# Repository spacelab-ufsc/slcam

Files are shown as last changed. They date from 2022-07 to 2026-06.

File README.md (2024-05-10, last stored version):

<h1 align="center">
    SLCam
    <br>
</h1>

<h4 align="center">Camera payload designed and developed by SpaceLab.</h4>

<p align="center">
    <a href="https://github.com/spacelab-ufsc/spacelab#versioning">
        
    </a>
    <a href="https://github.com/spacelab-ufsc/slcam/releases">
        
    </a>
    <a href="https://github.com/spacelab-ufsc/slcam/releases">
        
    </a>
    <a href="https://github.com/spacelab-ufsc/slcam/commits/main">
        
    </a>
    <a href="https://github.com/spacelab-ufsc/slcam/issues">
        
    </a>
    <a href="https://github.com/spacelab-ufsc/slcam/graphs/contributors">
        
    </a>
</p>

<p align="center">
    <a href="#overview">Overview</a> •
    <a href="#repository-organization">Repository Organizarion</a> •
    <a href="#releases">Releases</a> •
    <a href="#notes">Notes</a>
</p>

<p align="center">
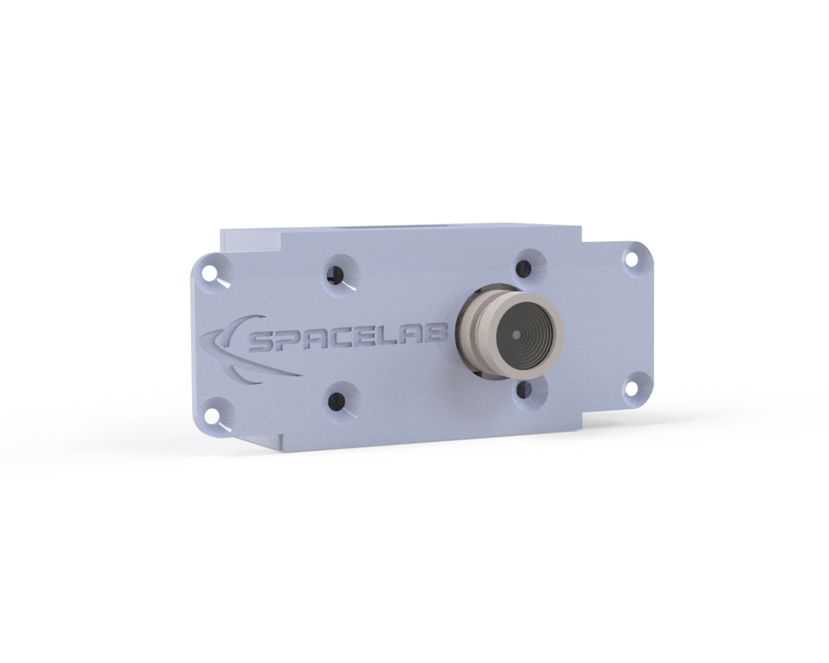
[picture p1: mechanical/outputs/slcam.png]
    
</p>

## Overview

The SLCam ("SpaceLab Camera") is a camera payload designed to be used in nanosatellite missions. The main object is to take pictures of the Earth from space. It's the first project from SpaceLab using cameras in payloads.

## Repository Organization

* docs: Technical documentation (including firmware, hardware, user guide, and datasheet).
* firmware: Firmware project (sources and configs).
* hardware: Hardware project (sources and outputs).
* mechanical: Mechanical project (sources and outputs).
* software: Software to communicate with the camera (sources).

## License

This project is open-source under three different licenses: GNU General Public License v3.0 for firmware sources, CERN Open Hardware License v2.0 for hardware and mechanical files, and CC BY-SA 4.0 for the documentation. Some third-part files and libraries are subjected to their specific terms and licenses.

## Releases

The SLCam software and hardware releases are synchronized in order to garantee compatibility. Then, using diferent versions might lead to unpredictable behavior. Refer to the [documentation](https://github.com/spacelab-ufsc/slcam/tree/main/doc) for compatibility notes.

## Notes

More info about the SpaceLab: [GitHub](https://github.com/spacelab-ufsc/spacelab) and [Website](https://spacelab.ufsc.br/en/home/).

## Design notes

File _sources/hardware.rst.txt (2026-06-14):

.. hardware.rst

   Copyright The SLCam Contributors.

   SLCam Documentation

   This work is licensed under the Creative Commons Attribution-ShareAlike 4.0
   International License. To view a copy of this license,
   visit http://creativecommons.org/licenses/by-sa/4.0/.

********
Hardware
********

This chapter presents a description of the hardware project of the SLCam payload. As the primary reference, a block diagram can be seen in :numref:`fig:block-diagram`.

.. _fig:block-diagram:

.. figure:: img/block-diagram.*
      :width: 80%
      :align: center
      :alt: Block diagram 

      Block diagram of the SLCam hardware.

As can be seen in the block diagram, the hardware design of the module can be divided into two parts: the image sensor and the camera control board.

The following sections present a further description of each part of the hardware.

Image Sensor
============

The image sensor used in the SLCam module is the Arducam Mini 2MP Plus camera module :cite:`arducam`. This module is based on the OV2640 image sensor and provides a compact and low-power solution for embedded imaging applications. It supports image resolutions up to 1600 :math:`\times` 1200 pixels and communicates with the main controller through an I\ :sup:`2`\ C and an SPI interface.

In addition to integrating the image sensor itself, the module also includes onboard FIFO memory, allowing image buffering and simplified data acquisition by the host microcontroller. Due to its reduced size, low power consumption, and ease of integration, the Arducam Mini 2MP Plus was selected as the primary imaging device for the SLCam payload.

A photograph of the Arducam Mini 2MP Plus module is shown in :numref:`fig:arducam`. The top and bottom view of the board can also be seen in :numref:`fig:arducam-top-bottom`.

.. _fig:arducam:

.. figure:: img/arducam-2mp.png
      :width: 50%
      :align: center
      :alt: Arducam Mini 2MP

      Arducam Mini 2MP Plus.

.. _fig:arducam-top-bottom:

.. subfigure:: AB
    :layout-sm: A|B
    :gap: 8px
    :subcaptions: below
    :name: arducam_board
    :class-grid: outline
    :align: center

    .. image:: img/arducam-top.jpg
        :width: 70%
        :align: center
        :alt: Top view.

    .. image:: img/arducam-bottom.jpg
        :width: 70%
        :align: center
        :alt: Bottom view.

    Arducam Mini 2MP Plus top and bottom view.

The internal architecture of the Arducam Mini 2MP Plus module is illustrated in the block diagram shown in :numref:`fig:arducam-block-diagram`. The module is centered around the OV2640 image sensor and the ArduChip controller, which is responsible for image acquisition, buffering, and communication with the host system.

.. _fig:arducam-block-diagram:

.. figure:: img/arducam-block-diagram.png
      :width: 100%
      :align: center
      :alt: Block diagram Arducam

      Block diagram of the Arducam Mini 2MP Plus.

The image sensor is connected to the ArduChip through a dedicated camera interface, responsible for receiving pixel data and synchronization signals. Internally, the ArduChip includes a Frame Buffer Finite State Machine (FSM) and memory timing control logic, which manage the storage and retrieval of image data from the external FIFO memory. This architecture allows complete image frames to be temporarily buffered before being transmitted to the host microcontroller.

Communication with the host system is performed through an SPI slave interface, using the standard signals CS, MISO, MOSI, and SCLK. Additionally, the image sensor configuration is performed through an I\ :sup:`2`\ C-compatible interface using the SDA and SCL signals. A register module is also available inside the ArduChip, enabling configuration and control of the camera operation and memory management functions.

The connection between the Arducam module and the control board is made using an 8-pin vertical header connector. Since the Arducam module originally comes with a horizontal pin header connector, it must be replaced with a vertical connector during the assembly of the SLCam device.

For integration purposes, the dimensions of the Arducam board are available in :numref:`fig:arducam-dimensions`.

.. _fig:arducam-dimensions:

.. figure:: img/arducam-dimensions.png
      :width: 50%
      :align: center
      :alt: Arducam Mini 2MP Dimensions

      Arducam Mini 2MP Plus dimensions.

Controller Board
================

The camera control board is responsible for managing the operation of the SLCam module and interfacing the image sensor with external systems. As illustrated in the block diagram, the control board is centered around the STM32F103C8T6 microcontroller, which performs image acquisition control, communication management, data processing, and system supervision. The microcontroller communicates with the image sensor through SPI and I\ :sup:`2`\ C interfaces, using a dedicated image sensor connector that also provides the 3V3 power supply required by the camera module.

For non-volatile data storage, the control board includes a W25Q128JVSIM NOR Flash memory device connected through the SPI bus. This memory is used for image storage, buffering, and firmware-related data retention. External communication with host systems can be performed through both SPI and CAN interfaces, providing redundant communication channels for control and image transfer operations. The CAN interface is implemented using the TCAN330GD CAN transceiver, which provides the physical layer interface between the microcontroller and the external CAN bus network.

The board also provides dedicated UART and JTAG connectors for debugging and firmware programming purposes. The UART interface allows access to system logs and command-line interaction, while the JTAG connector enables firmware upload and low-level debugging of the microcontroller.

Power distribution and protection are managed through the TPS2010AD power switch device, which controls the power supplied to the image sensor module. The switch is controlled by a GPIO signal from the microcontroller, allowing the firmware to enable or disable the camera module dynamically for power management and fault recovery purposes. Together, these components form a compact and modular camera controller architecture suitable for embedded and small satellite applications.

A picture of the controller board is shown in :numref:`fig:controller`.

.. _fig:controller:

.. figure:: img/controller-overview.png
      :width: 50%
      :align: center
      :alt: Controller board

      Controller board.

A list with the components and part numbers of the controller board is available in :numref:`tab:controller-bom`.

.. _tab:controller-bom:

.. list-table:: Components of the controller board.
   :widths: 30 35 25 10
   :width: 100%
   :align: center
   :header-rows: 1

   * * Component
     * Description
     * Part Number
     * Quantity
   * * Microcontroller
     * ARM Cortex M3
     * STM32F103C8T6
     * 1
   * * Flash Memory
     * NOR 128 Mbit
     * W25Q128JVSIM TR
     * 1
   * * Switch
     * Load switch
     * TPS2010AD
     * 1
   * * CAN Transceiver
     * CAN transceiver
     * TCAN330GD
     * 1
   * * SPI/3V3 Connector
     * PicoBlade 6 pin
     * 532610671
     * 1
   * * UART Connector
     * PicoBlade 3 pin
     * 532610371
     * 1
   * * CAN Connector
     * PicoBlade 3 pin
     * 532610371
     * 1
   * * Image Sensor Connector
     * Female header 8 pin straight
     * -
     * 1
   * * JTAG Connector
     * Male header 4 pin angled
     * -
     * 1
   * * Crystal
     * 8 MHz crystal
     * ECS-80-10-33-CHN-TR3
     * 1

Printed Circuit Board
*********************

The controller board PCB was developed using the KiCad v5 tool :cite:`kicad` and was designed as a compact four-layer board. The multilayer structure improves signal integrity, simplifies power distribution, and reduces electromagnetic interference, which is particularly important for embedded systems operating with high-speed digital interfaces such as SPI and CAN.

The PCB was designed using standard FR-4 material with a total thickness of 1.6 mm. The engineering model uses a HASL (Hot Air Solder Leveling) surface finish, while the flight model is planned to use an ENIG (Electroless Nickel Immersion Gold) finish to improve corrosion resistance and soldering reliability. No special dielectric or impedance-controlled stack-up requirements were necessary for the current design.

Mechanically, the controller board measures 41.7 :math:`\times` 27.4 mm and includes four mounting holes with a diameter of 3.2 mm, allowing secure integration into the payload mechanical structure. The compact dimensions of the PCB contribute to the reduced size and mass of the SLCam module, making it suitable for small satellite and embedded imaging applications.

Top and bottom views of the controller board are presented in :numref:`fig:controller-board-top-bottom`, highlighting the component placement and routing distribution across the PCB layers.

.. _fig:controller-board-top-bottom:

.. subfigure:: AB
    :layout-sm: A|B
    :gap: 8px
    :subcaptions: below
    :name: controler_board
    :class-grid: outline
    :align: center

    .. image:: img/controller-top.png
        :width: 60%
        :align: center
        :alt: Top view.

    .. image:: img/controller-bottom.png
        :width: 60%
        :align: center
        :alt: Bottom view.

    Controller board top and bottom view.

Integration Between the Image Sensor and the Controller Board
=============================================================

The SLCam module is composed of two independent electronic boards: the Arducam Mini 2MP Plus image sensor board and the custom-developed controller board. The integration between these two boards is illustrated in :numref:`fig:boards-integration`.

.. _fig:boards-integration:

.. figure:: img/boards-integration.png
   :width: 60%
   :align: center
   :alt: Boards integration

   Integration between the Arducam image sensor board and the controller board.

The controller board is positioned below the image sensor module and is responsible for power distribution, communication management, image acquisition control, and external interfacing of the SLCam module. The Arducam board is mounted above the controller board using metallic spacers that provide mechanical support, structural rigidity, and controlled spacing between the two PCBs.

The electrical connection between both boards is performed through a vertical pin header interface. Through this connector, the controller board provides the required 3V3 power supply to the image sensor module and establishes the SPI and I\ :sup:`2`\ C communication buses used for image transfer and camera configuration. The SPI interface is responsible for image data acquisition from the ArduChip FIFO memory, while the I\ :sup:`2`\ C bus is used for configuring the OV2640 image sensor registers and operating parameters.

As shown in :numref:`fig:boards-integration`, the optical axis of the camera module is aligned with the center of the mechanical enclosure opening, allowing unobstructed image acquisition. The stacked PCB arrangement contributes to reducing the overall footprint of the payload while maintaining accessibility to the external electrical interfaces located on the controller board.

Additionally, insulating foam spacers are positioned between the boards to reduce mechanical vibrations, minimize stress concentration during assembly, and prevent unintended contact between electronic components mounted on opposite PCB surfaces. This integration approach results in a compact, lightweight, and mechanically robust imaging subsystem suitable for embedded and nanosatellite applications.

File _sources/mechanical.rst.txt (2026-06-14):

.. mechanical.rst

   Copyright The SLCam Contributors.

   SLCam Documentation

   This work is licensed under the Creative Commons Attribution-ShareAlike 4.0
   International License. To view a copy of this license,
   visit http://creativecommons.org/licenses/by-sa/4.0/.

**********
Mechanical
**********

This chapter describes the mechanical design of the SLCam module, including the structural architecture, manufacturing process, materials, dimensions, and external mechanical interfaces. The mechanical project was developed using the SolidWorks CAD software :cite:`solidworks`, allowing the creation of the complete three-dimensional model of the payload and the verification of the assembly and integration requirements.

The SLCam mechanical structure was designed to provide adequate protection for the electronic boards and optical components while maintaining reduced size and mass, which are critical requirements for nanosatellite applications. The mechanical assembly is composed of a machined aluminum enclosure, internal support spacers, fastening screws, and the optical opening for the camera lens. All parts of the mechanical assembly are shown in :numref:`fig:slcam-parts`.

.. _fig:slcam-parts:

.. figure:: img/assembly-parts.jpg
   :width: 100%
   :align: center
   :alt: SLCam parts

   Exploded view of the SLCam mechanical assembly.

As illustrated in :numref:`fig:slcam-parts`, the mechanical structure is composed of two main enclosure parts: the main body and the bottom cover. The main body accommodates the controller board and the image sensor assembly, while the removable cover provides access to the internal electronics during integration and maintenance procedures. Metallic spacers and fastening screws are used to mechanically secure the printed circuit boards and maintain the required alignment between the controller board and the image sensor module.

The optical interface is located on the upper surface of the enclosure, where a circular opening allows the camera lens to capture images outside the module. The enclosure also includes external openings for electrical connectors and integration interfaces. Additionally, engraved inscriptions are present on the external surfaces of the case for identification and traceability purposes.

The enclosure was manufactured from 7075 aluminum alloy using a CNC milling process. This material was selected due to its high mechanical strength, low density, and suitability for aerospace and embedded applications. After machining, all external and internal surfaces of the enclosure received an anodization treatment to improve corrosion resistance, surface hardness, and long-term durability.

The SLCam module has compact dimensions suitable for CubeSat-class payloads. The dimensions of the main structural core are 54.0 :math:`\times` 26.1 :math:`\times` 34.1 mm, while the overall envelope dimensions are 82.2 :math:`\times` 34.8 :math:`\times` 34.1 mm. The total mass of the module is approximately 67 g, including the enclosure, electronics, fasteners, and optical assembly.

For structural integration into the satellite platform, the mechanical case includes mounting holes compatible with M3 screws, allowing secure attachment to the spacecraft structure. The positions and spacing of these mounting interfaces are described in the following sections.

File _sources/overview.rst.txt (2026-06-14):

.. overview.rst

   Copyright The SLCam Contributors.

   SLCam Documentation

   This work is licensed under the Creative Commons Attribution-ShareAlike 4.0
   International License. To view a copy of this license,
   visit http://creativecommons.org/licenses/by-sa/4.0/.

********
Overview
********

The SLCam is a compact camera payload developed by SpaceLab at the Federal University of Santa Catarina (UFSC) for nanosatellite and embedded imaging applications. The primary objective of the module is to capture images of the Earth from orbit, providing a low-cost and modular imaging solution suitable for CubeSat-class missions and technology demonstration platforms. The SLCam project also represents the first SpaceLab payload specifically designed around camera-based image acquisition systems. A picture of the camera module can be seen in :numref:`fig:slcam-mounted`.

.. _fig:slcam-mounted:

.. figure:: img/slcam-small.png
      :width: 70%
      :align: center
      :alt: SLCam 

      SLCam.

The payload architecture is divided into two main subsystems: the image sensor module and the camera controller board. The imaging subsystem is based on the Arducam Mini 2MP Plus module, which integrates the OV2640 image sensor and onboard FIFO memory for image buffering. The controller board, built around the STM32F103C8T6 microcontroller, is responsible for image acquisition control, communication management, data storage, and system supervision. The module also includes external NOR Flash memory for image storage and supports both SPI and CAN interfaces for communication and image transfer.

From the software perspective, the SLCam firmware is organized using a layered architecture based on FreeRTOS, separating low-level hardware abstraction, peripheral drivers, device management, and application tasks. The firmware also incorporates software validation mechanisms such as static analysis, unit testing, and hardware integration testing, contributing to the reliability and maintainability of the system. Automated verification workflows are executed through GitHub Actions, enabling continuous integration and validation of the firmware throughout the development process.

Mechanically, the payload was designed as a compact and lightweight module suitable for constrained satellite platforms. The controller PCB uses a four-layer FR-4 stack-up and integrates all the required interfaces for programming, debugging, control, and data transfer. Together, the hardware, firmware, mechanical, and software components form a complete imaging payload platform intended for research, educational, and experimental space missions.

Specifications
==============

The SLCam is a compact imaging payload designed for nanosatellite and embedded applications. The module integrates the Arducam Mini 2MP Plus image sensor together with a dedicated controller board based on the STM32F103C8T6 ARM Cortex-M3 microcontroller operating at 72 MHz. The system also includes external NOR Flash memory for non-volatile image storage and supports multiple communication interfaces for control, debugging, and programming purposes.

The main specifications of the SLCam module are available in :numref:`tab:slcam-specs`.

.. _tab:slcam-specs:

.. list-table:: General specifications of the SLCam module.
    :widths: 30 30
    :width: 60%
    :align: center
    :header-rows: 1

    *
      - **Parameter**
      - **Value**
    *
      - *Sensor type*
      - RGB
    *
      - *Image Sensor*
      - OV2640
    *
      - *Pixel size*
      - 2.2 :math:`\times` 2.2 :math:`\mu` m
    *
      - *Max. Resolution*
      - 1600 :math:`\times` 1200 px
    *
      - *Shutter*
      - Rolling Shutter
    *
      - *Field of View (FoV)*
      - :math:`68^{\circ}` (6 mm) (**TBC**)
    *
      - *Processor*
      - STM32 ARM Cortex-M3
    *
      - *Storage*
      - 16 MB (Flash NOR)
    *
      - *Power Supply*
      - 3V3 @ 140 mA (**TBC**)
    *
      - *Control/Data Interface*
      - SPI and/or CAN
    *
      - *Debug Interface*
      - UART
    *
      - *Programming*
      - JTAG
    *
      - *Operating System*
      - FreeRTOS
    *
      - *Dimensions*
      - | 54.0 :math:`\times` 26.1 :math:`\times` 34.1 mm (main core)
        | 82.2 :math:`\times` 34.8 :math:`\times` 34.1 mm (envelope)
    *
      - *Weight*
      - 67 g

Product tree
============

The product tree of the SLCam payload can be divided into five branches: hardware, firmware, mechanical, software and documentation. A diagram of the product tree is available in :numref:`fig:product-tree`.

.. _fig:product-tree:

.. figure:: img/product-tree.*
      :width: 100%
      :align: center
      :alt: Product tree

      Product tree of the SLCam Payload.

Each branch and element of the product tree are described in the next chapters of this documentation.

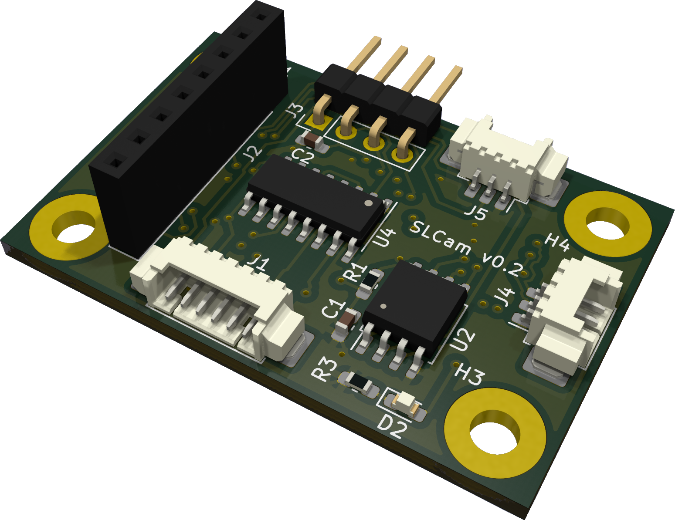
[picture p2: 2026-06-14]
_images/controller-overview.png

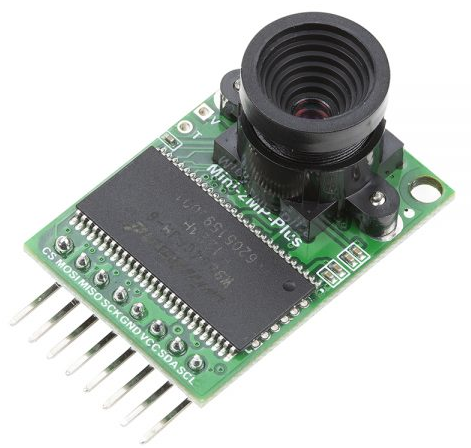
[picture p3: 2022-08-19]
_images/arducam-2mp.png

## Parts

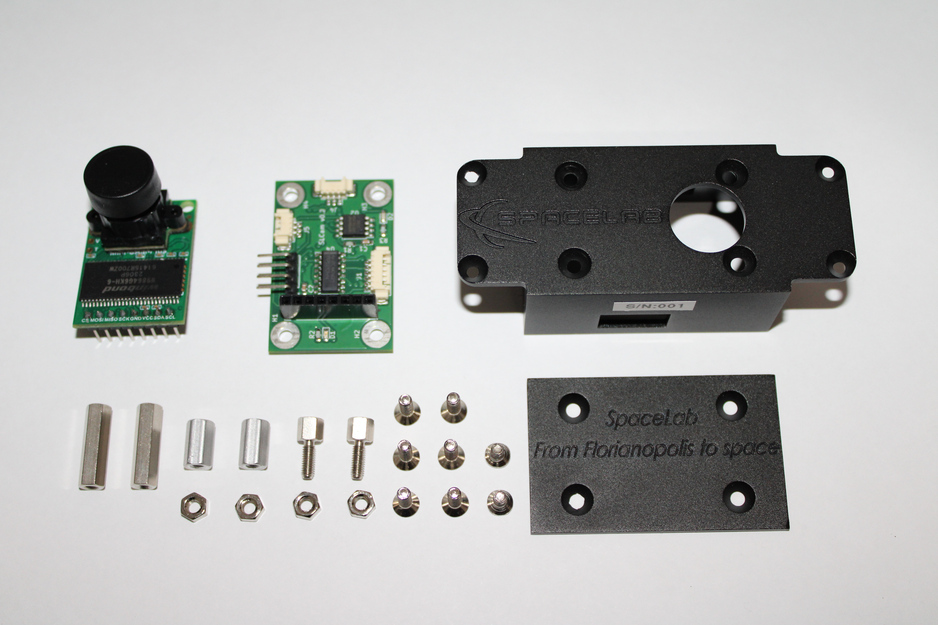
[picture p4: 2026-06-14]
_images/assembly-parts.jpg

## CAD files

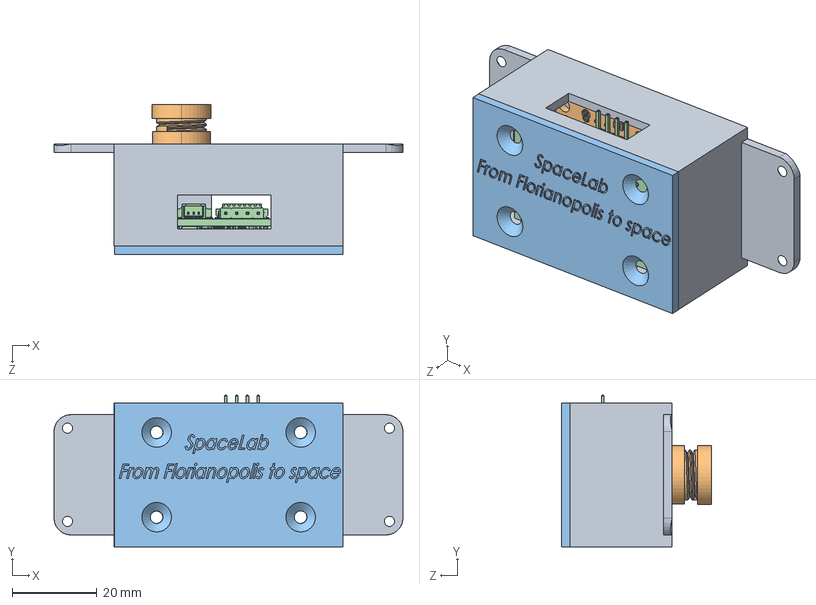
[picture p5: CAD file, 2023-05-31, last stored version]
mechanical/slb-slc-case.sldasm
82.4 x 35.8 x 35.3 mm
Placa traseira camera
UC-474B0067
Peça2

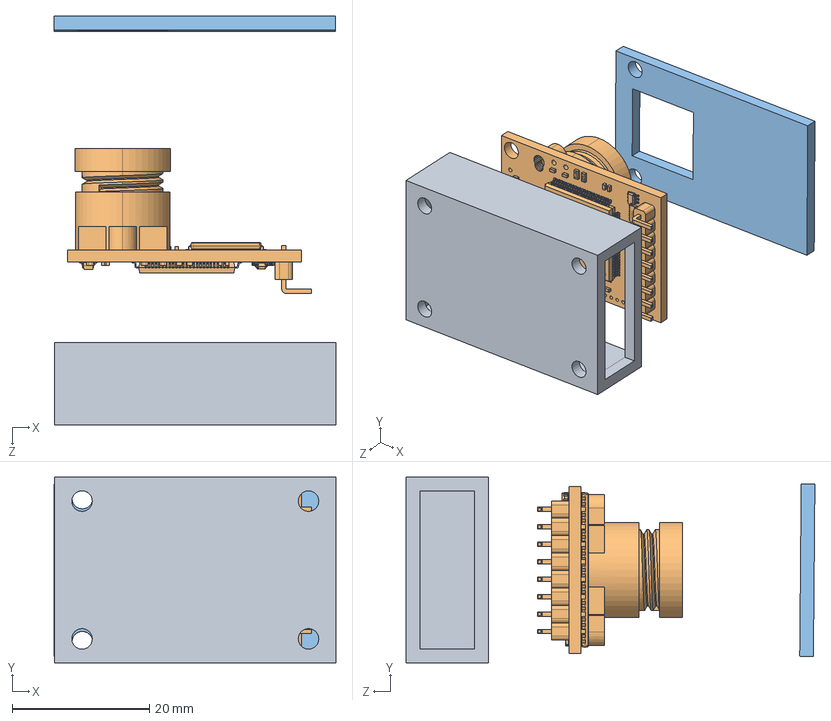
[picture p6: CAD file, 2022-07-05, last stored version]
mechanical/slcam-mount.sldasm
41.1 x 27.1 x 59.6 mm
Placa traseira camera
UC-474(B0067)
Placa frontal camera

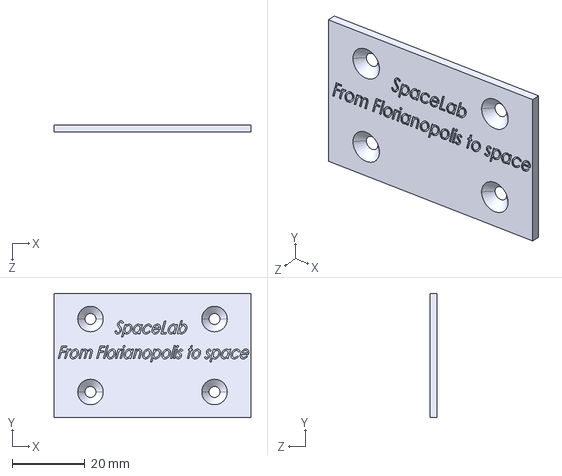
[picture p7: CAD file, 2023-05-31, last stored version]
mechanical/outputs/slb-slc-case-back.step
54.0 x 34.0 x 2.00 mm

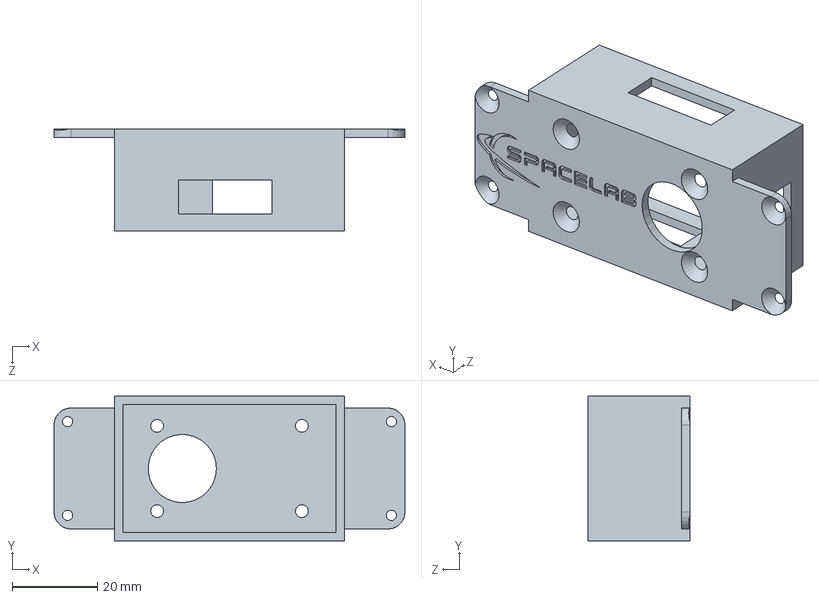
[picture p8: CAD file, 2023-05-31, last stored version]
mechanical/slb-slc-case-front.sldprt
82.4 x 34.0 x 24.0 mm

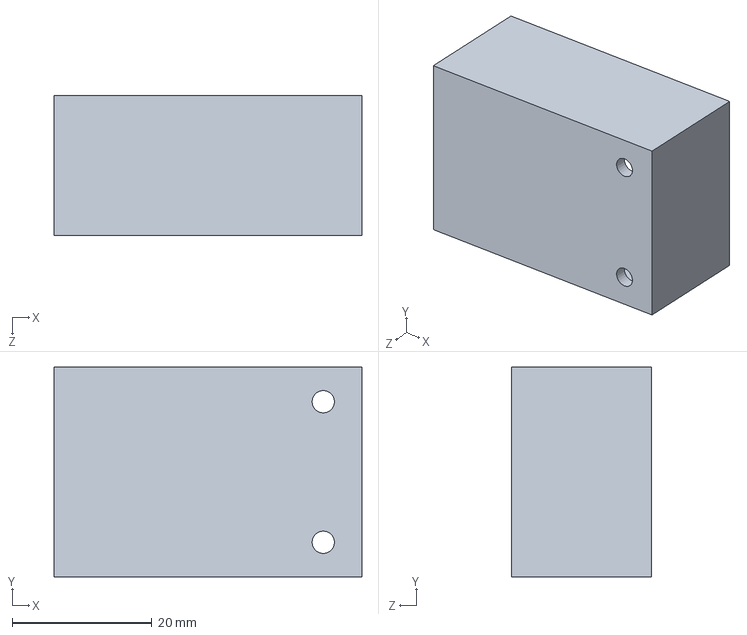
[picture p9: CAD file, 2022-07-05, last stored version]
mechanical/slcam-front-shield-v2.sldprt
44.0 x 30.0 x 20.0 mm

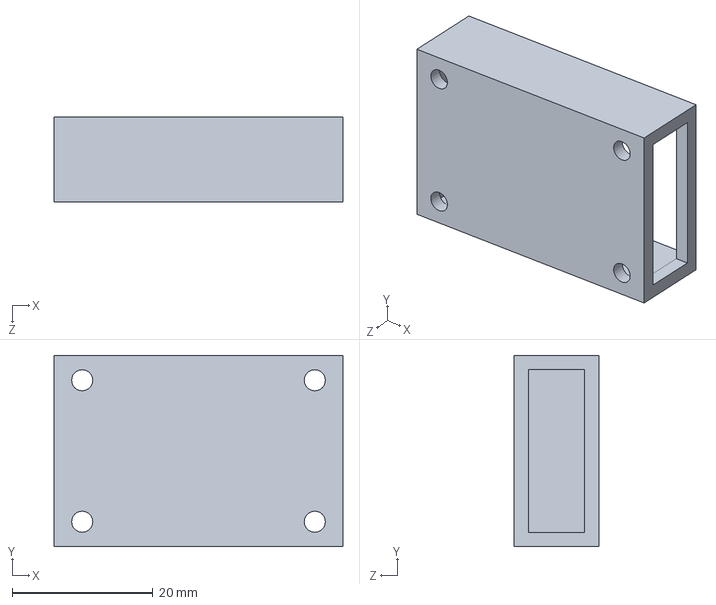
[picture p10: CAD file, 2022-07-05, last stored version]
mechanical/Placa traseira camera.SLDPRT
41.0 x 27.1 x 12.0 mm

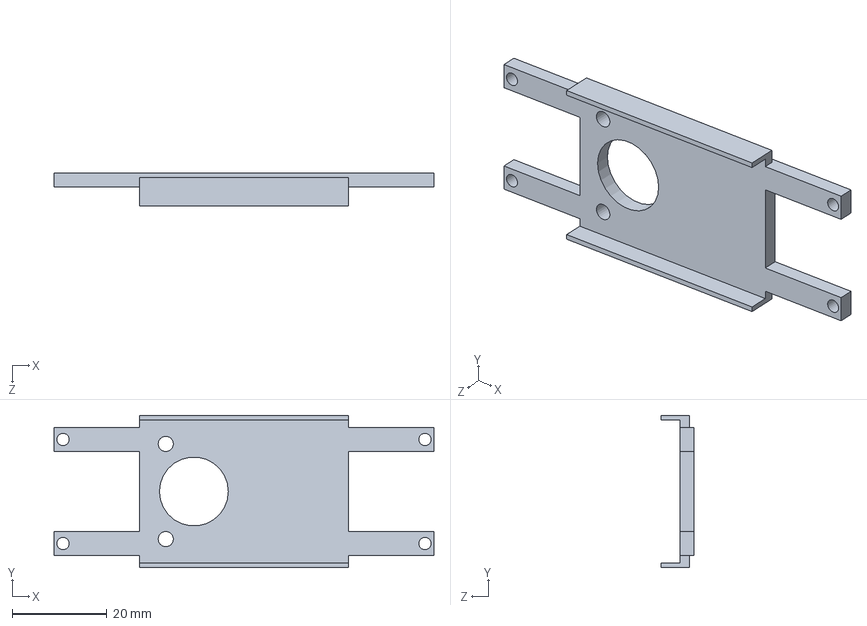
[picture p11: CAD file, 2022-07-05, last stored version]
mechanical/Placa traseira camera_V2.SLDPRT
80.0 x 32.1 x 7.00 mm

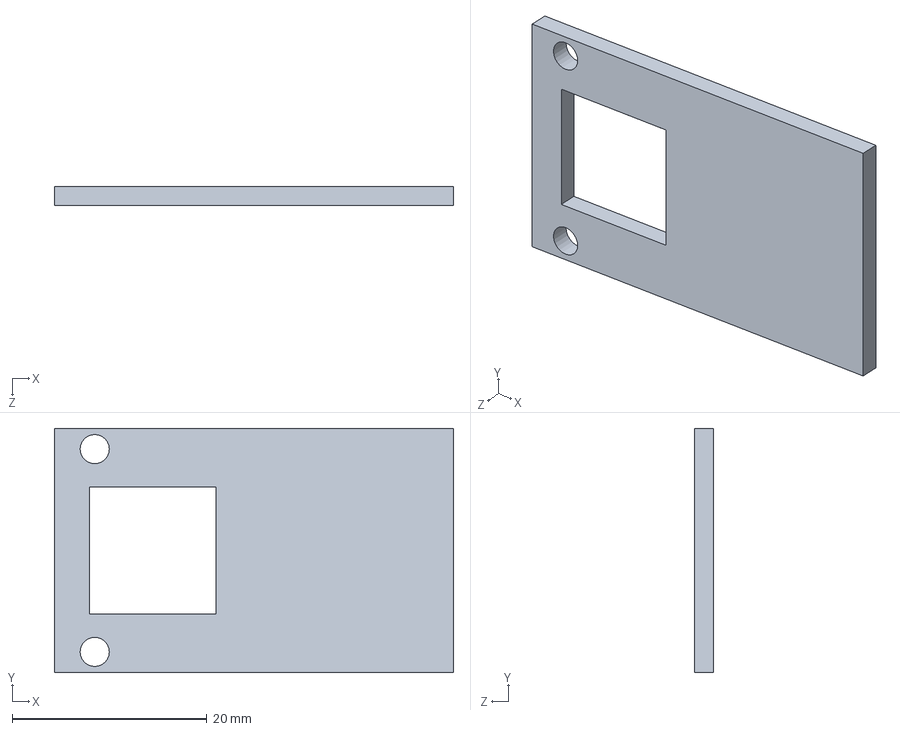
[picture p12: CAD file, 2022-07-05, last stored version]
mechanical/Placa frontal camera.SLDPRT
41.0 x 25.1 x 2.00 mm

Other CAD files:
mechanical/outputs/slb-slc-case-front.step
mechanical/Placa frontal camera_V2.STL
mechanical/Placa traseira camera_V2.STL
mechanical/slb-slc-case-back.slddrw
mechanical/slb-slc-case-front.slddrw
mechanical/slb-slc-case.sldprt
mechanical/slcam-back-shield-v2.stl
mechanical/slcam-front-shield-v2.stl

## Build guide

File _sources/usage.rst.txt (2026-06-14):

.. usage.rst

   Copyright The SLCam Contributors.

   SLCam Documentation

   This work is licensed under the Creative Commons Attribution-ShareAlike 4.0
   International License. To view a copy of this license,
   visit http://creativecommons.org/licenses/by-sa/4.0/.

******************
Usage Instructions
******************

Assembly
========

This section describes the recommended assembly procedure for the SLCam module. The assembly sequence presented below follows the order illustrated in the figures and ensures the correct mechanical alignment between the controller board, the image sensor module, and the external enclosure.

#. **Prepare the base plate and fastening screws**

Start the assembly by positioning the four mounting screws into the base plate holes, as shown in :numref:`fig:assembly-step1`.

.. _fig:assembly-step1:

.. figure:: img/step1.jpg
      :width: 100%
      :align: center
      :alt: Assembly step 1

      Step 1 of the assembly sequence.

#. **Fix the screws using nuts**

Secure the screws to the base plate using the corresponding nuts on the opposite side of the plate. This step creates the mechanical support structure used for mounting the electronic boards.

.. _fig:assembly-step2:

.. figure:: img/step2.jpg
      :width: 100%
      :align: center
      :alt: Assembly step 2

      Step 2 of the assembly sequence.

#. **Install the controller board**

Place the controller board onto the mounted screws, aligning the PCB mounting holes with the screw positions, as illustrated in :numref:`fig:assembly-step3`.

.. _fig:assembly-step3:

.. figure:: img/step3.jpg
      :width: 100%
      :align: center
      :alt: Assembly step 3

      Step 3 of the assembly sequence.

#. **Install the metallic spacers**

Attach the metallic spacers above the controller board using the threaded screws. These spacers define the vertical distance between the controller board and the image sensor module while also providing mechanical rigidity to the structure.

.. _fig:assembly-step4:

.. figure:: img/step4.jpg
      :width: 100%
      :align: center
      :alt: Assembly step 4

      Step 4 of the assembly sequence.

#. **Prepare the image sensor module**

Install the fastening screws and support spacers on the Arducam image sensor board. Protective foam pads may also be positioned near the mounting points to reduce mechanical stress and vibrations during operation.

.. _fig:assembly-step5:

.. figure:: img/step5.jpg
      :width: 100%
      :align: center
      :alt: Assembly step 5

      Step 5 of the assembly sequence.

#. **Mount the image sensor board**

Position the image sensor board above the controller board, aligning the spacers and connector interfaces. The camera module should remain parallel to the controller board to ensure proper optical alignment.

.. _fig:assembly-step6:

.. figure:: img/step6.jpg
      :width: 100%
      :align: center
      :alt: Assembly step 6

      Step 6 of the assembly sequence.

#. **Connect the image sensor interface**

Carefully connect the image sensor board to the controller board through the dedicated header connector. Verify that all connector pins are properly aligned before applying force to the assembly.

.. _fig:assembly-step7:

.. figure:: img/step7.jpg
      :width: 100%
      :align: center
      :alt: Assembly step 7

      Step 7 of the assembly sequence.

#. **Verify the internal assembly**

After the installation of both electronic boards, inspect the mechanical alignment, connector engagement, and spacer fixation. An assembled internal structure is shown in :numref:`fig:assembly-step8`.

.. _fig:assembly-step8:

.. figure:: img/step8.jpg
      :width: 100%
      :align: center
      :alt: Assembly step 8

      Step 8 of the assembly sequence.

#. **Insert the assembly into the enclosure**

Position the assembled electronic structure inside the aluminum enclosure. Ensure that the camera lens is aligned with the optical opening of the case and that the external connectors are properly positioned relative to the case openings.

.. _fig:assembly-step9:

.. figure:: img/step9.jpg
      :width: 100%
      :align: center
      :alt: Assembly step 9

      Step 9 of the assembly sequence.

#. **Fix the top cover**

Install the top cover of the enclosure and secure it using the fastening screws, as shown in :numref:`fig:assembly-step10`.

.. _fig:assembly-step10:

.. figure:: img/step10.jpg
      :width: 100%
      :align: center
      :alt: Assembly step 10

      Step 10 of the assembly sequence.

#. **Final inspection**

After completing the assembly, perform a final inspection of the module, verifying the mechanical fixation, connector accessibility, optical alignment, and enclosure closure integrity. The final assembled SLCam module is illustrated in :numref:`fig:assembly-step11`.

.. _fig:assembly-step11:

.. figure:: img/step11.jpg
      :width: 100%
      :align: center
      :alt: Assembly step 11

      Step 11 of the assembly sequence.

The assembly procedure described above is intended for laboratory integration and prototype assembly. During flight-model assembly, additional procedures such as torque control, thread-locking compounds, cleanliness verification, and vibration-resistant fixation methods may also be required.

Firmware Upload
===============

.. note::
   TODO

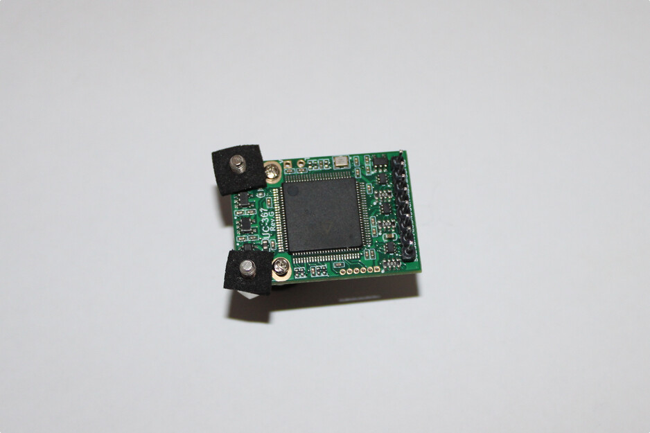
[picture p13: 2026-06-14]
_images/step7.jpg

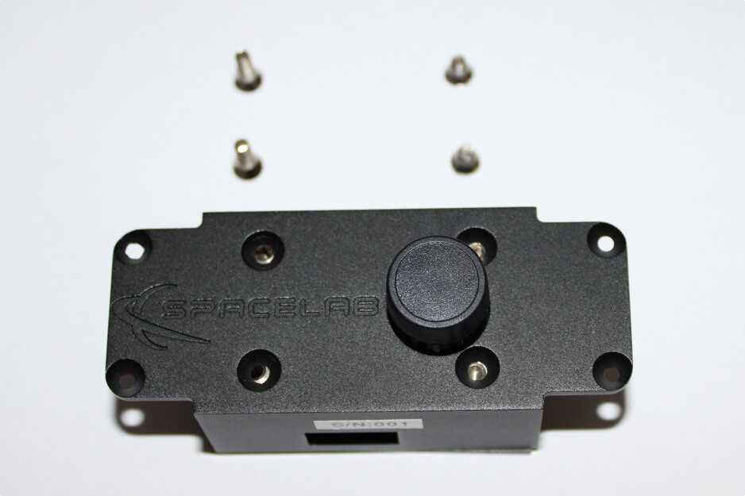
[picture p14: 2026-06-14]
_images/step10.jpg

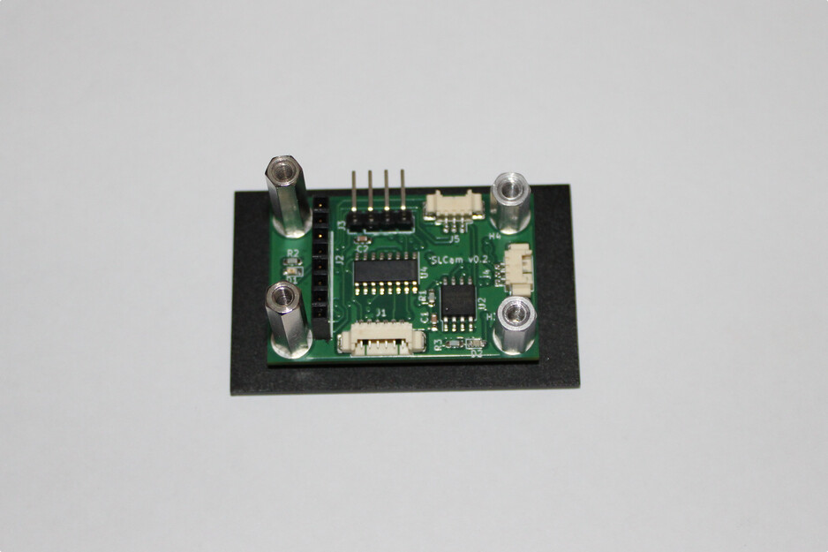
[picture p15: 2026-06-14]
_images/step5.jpg

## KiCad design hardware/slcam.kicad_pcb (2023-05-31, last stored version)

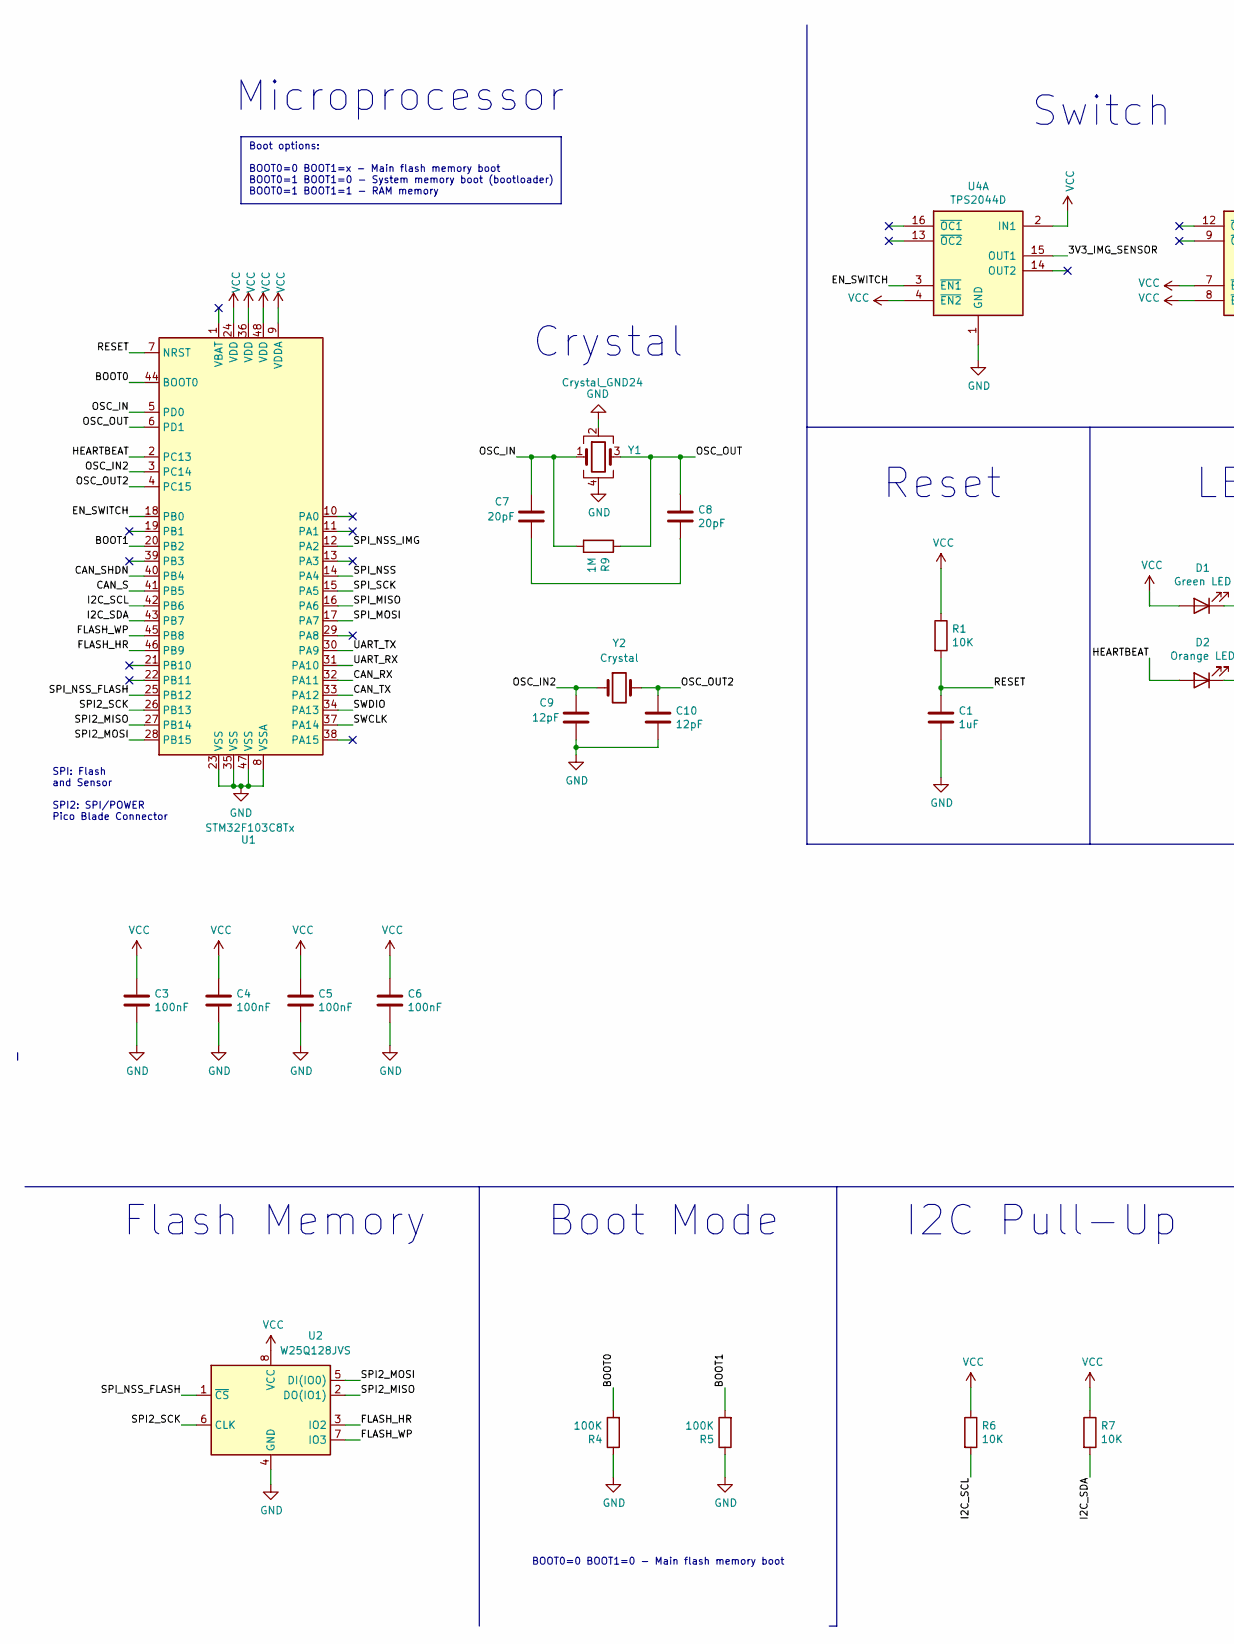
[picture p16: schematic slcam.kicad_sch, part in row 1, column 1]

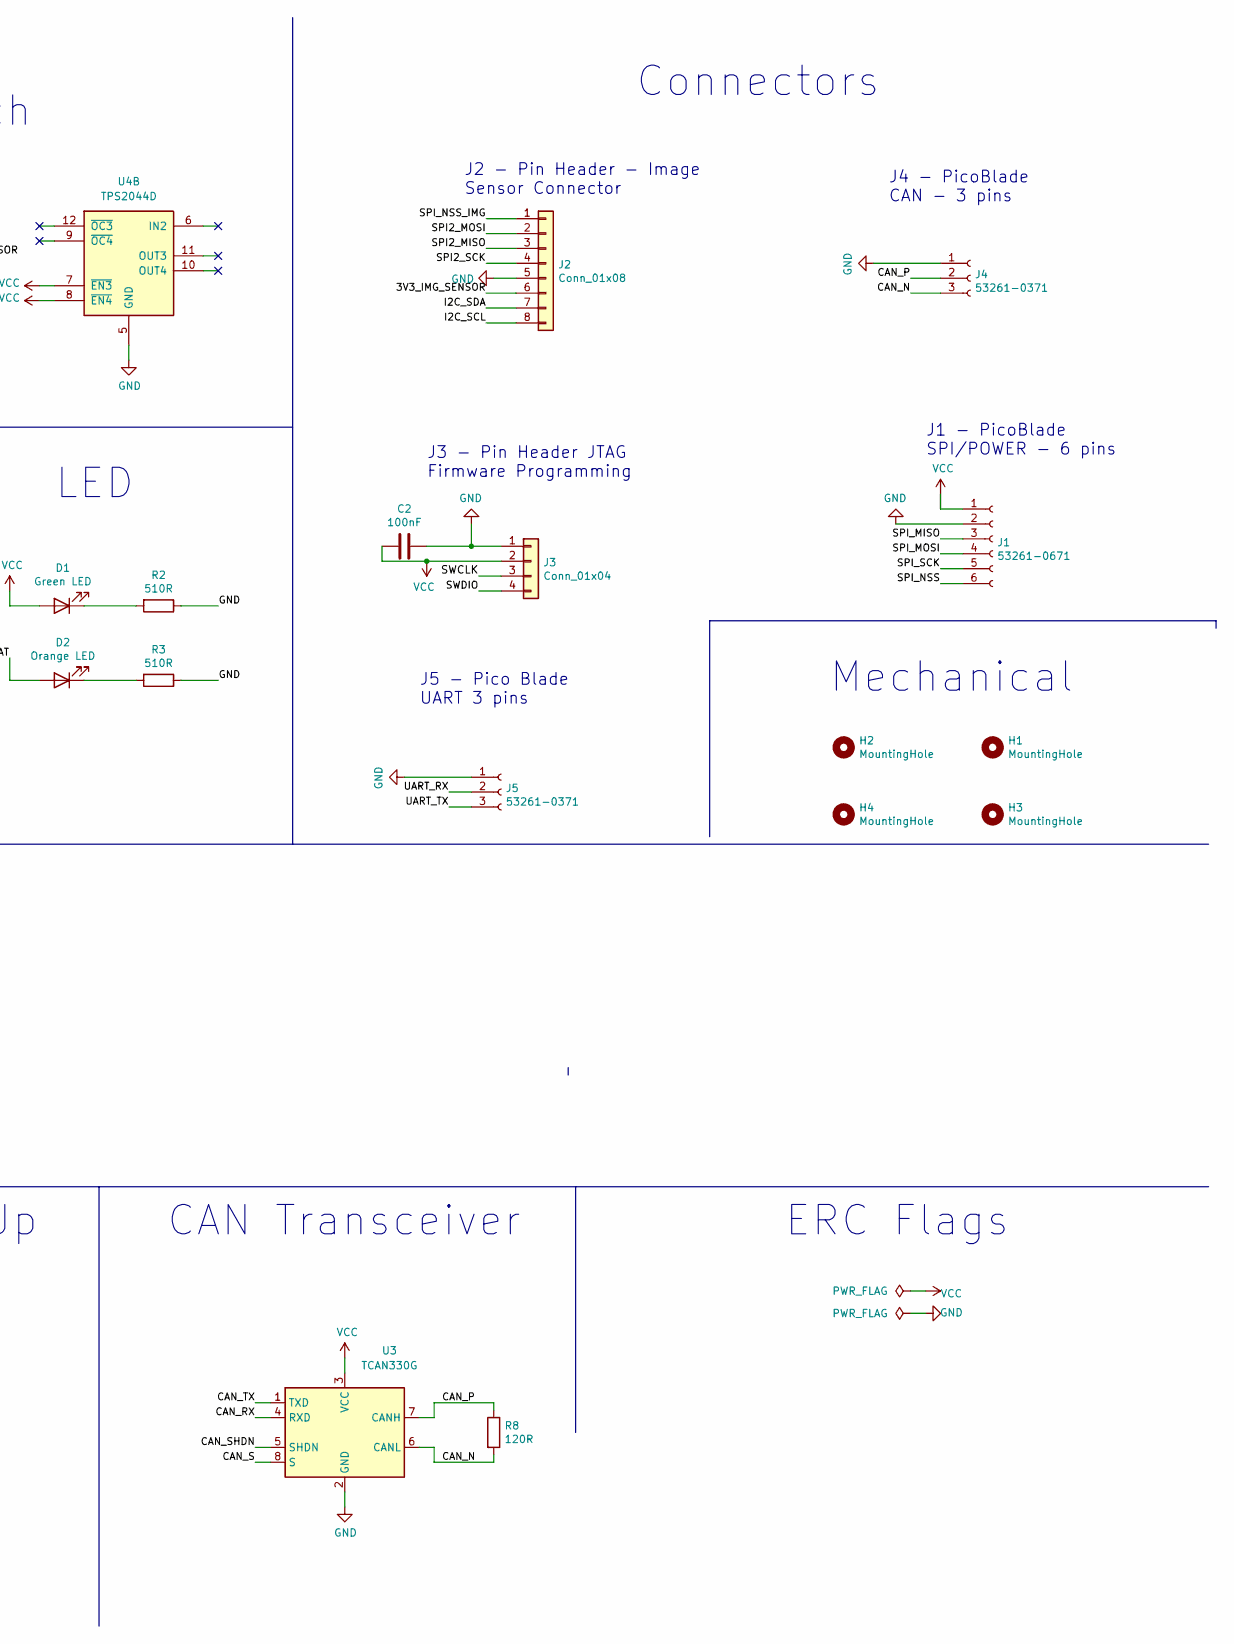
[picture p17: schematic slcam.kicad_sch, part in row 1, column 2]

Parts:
C1: 1uF; C_0603_1608Metric_Pad1.05x0.95mm_HandSolder; Partnumber GCJ188R71E105KA01D
C2, C3, C4, C5, C6: 100nF; C_0603_1608Metric_Pad1.05x0.95mm_HandSolder; Partnumber C0603C104K5RAC3121
C7, C8: 20pF; C_0603_1608Metric_Pad1.05x0.95mm_HandSolder; Partnumber CBR06C200J5GACAUTO
C9, C10: 12pF; C_0603_1608Metric_Pad1.08x0.95mm_HandSolder; Partnumber CL21C120FBANNNC
D1: Green LED; LED_0603_1608Metric_Pad1.05x0.95mm_HandSolder; Partnumber 150060VS75003
D2: Orange LED; LED_0603_1608Metric_Pad1.05x0.95mm_HandSolder; Partnumber CSL1901DW1
H1, H2, H3, H4: MountingHole; MountingHole_3.2mm_M3_Pad
J1: 53261-0671; Molex_PicoBlade_53261-0671_1x06-1MP_P1.25mm_Horizontal; Partnumber 53261-0671
J2: Conn_01x08; PinHeader_1x08_P2.54mm_Vertical; Partnumber SSQ-108-03-G-S
J3: Conn_01x04; PinHeader_1x04_P2.54mm_Vertical; Partnumber 5-146305-4
J4, J5: 53261-0371; Molex_PicoBlade_53261-0371_1x03-1MP_P1.25mm_Horizontal; Partnumber 53261-0371
R1, R6, R7: 10K; R_0603_1608Metric_Pad1.05x0.95mm_HandSolder; Partnumber MCT06030C1002FP500
R2, R3: 510R; R_0603_1608Metric_Pad1.05x0.95mm_HandSolder; Partnumber MCT06030C5100FP500
R4, R5: 100K; R_0603_1608Metric_Pad1.05x0.95mm_HandSolder; Partnumber MCT0603MC1003FP500
R8: 120R; R_0603_1608Metric_Pad1.05x0.95mm_HandSolder; Partnumber MCT06030C1200FP500
R9: 1M; R_0603_1608Metric_Pad1.05x0.95mm_HandSolder; Partnumber MCT06030C1004FP500
U1: STM32F103C8Tx; LQFP-48_7x7mm_P0.5mm; Partnumber STM32F103C8T6
U2: W25Q128JVS; SOIC-8_5.23x5.23mm_P1.27mm; Partnumber W25Q128JVSIM TR
U3: TCAN330G; SOIC-8_3.9x4.9mm_P1.27mm; Partnumber TCAN330GD
U4: TPS2044D; SOIC-16_3.9x9.9mm_P1.27mm; Partnumber TPS2044D
Y1: Crystal_GND24; Crystal_SMD_Abracon_ABM8G-4Pin_3.2x2.5mm; Partnumber ECS-80-10-33-CHN-TR3
Y2: Crystal; Crystal_SMD_MicroCrystal_CC7V-T1A-2Pin_3.2x1.5mm_HandSolder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; Partnumber ECS-.327-12.5-34S-TR

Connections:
/3V3_IMG_SENSOR: J2.6, U4.15 (OUT1)
/BOOT0: R4.2, U1.44 (BOOT0)
/BOOT1: R5.2, U1.20 (PB2)
/CAN_N: J4.3, R8.2, U3.6 (CANL)
/CAN_P: J4.2, R8.1, U3.7 (CANH)
/CAN_RX: U1.32 (PA11), U3.4 (RXD)
/CAN_S: U1.41 (PB5), U3.8 (S)
/CAN_SHDN: U1.40 (PB4), U3.5 (SHDN)
/CAN_TX: U1.33 (PA12), U3.1 (TXD)
/EN_SWITCH: U1.18 (PB0), U4.3 (~EN1)
/FLASH_HR: U1.46 (PB9), U2.3 (IO2)
/FLASH_WP: U1.45 (PB8), U2.7 (IO3)
/HEARTBEAT: D2.2 (A), U1.2 (PC13)
/I2C_SCL: J2.8, R6.2, U1.42 (PB6)
/I2C_SDA: J2.7, R7.2, U1.43 (PB7)
/OSC_IN: C7.1, R9.2, U1.5 (PD0), Y1.1
/OSC_IN2: C9.1, U1.3 (PC14), Y2.1
/OSC_OUT: C8.1, R9.1, U1.6 (PD1), Y1.3
/OSC_OUT2: C10.1, U1.4 (PC15), Y2.2
/RESET: C1.1, R1.2, U1.7 (NRST)
/SPI2_MISO: J2.3, U1.27 (PB14), U2.2 (DO(IO1))
/SPI2_MOSI: J2.2, U1.28 (PB15), U2.5 (DI(IO0))
/SPI2_SCK: J2.4, U1.26 (PB13), U2.6 (CLK)
/SPI_MISO: J1.3, U1.16 (PA6)
/SPI_MOSI: J1.4, U1.17 (PA7)
/SPI_NSS: J1.6, U1.14 (PA4)
/SPI_NSS_FLASH: U1.25 (PB12), U2.1 (~CS)
/SPI_NSS_IMG: J2.1, U1.12 (PA2)
/SPI_SCK: J1.5, U1.15 (PA5)
/SWCLK: J3.3, U1.37 (PA14)
/SWDIO: J3.4, U1.34 (PA13)
/UART_RX: J5.2, U1.31 (PA10)
/UART_TX: J5.3, U1.30 (PA9)
GND: C1.2, C2.1, C3.2, C4.2, C5.2, C6.2, C9.2, C10.2, J1.2, J2.5, J3.1, J4.1, J5.1, R2.1, R3.1, R4.1, R5.1, U1.8 (VSSA), U1.23 (VSS), U1.35 (VSS), U1.47 (VSS), U2.4 (GND), U3.2 (GND), U4.1 (GND), U4.5 (GND), Y1.2, Y1.4
unnamed: C7.2, C8.2
unnamed: D1.1 (K), R2.2
unnamed: D2.1 (K), R3.2
VCC: C2.2, C3.1, C4.1, C5.1, C6.1, D1.2 (A), J1.1, J3.2, R1.1, R6.1, R7.1, U1.9 (VDDA), U1.24 (VDD), U1.36 (VDD), U1.48 (VDD), U2.8 (VCC), U3.3 (VCC), U4.2 (IN1), U4.4 (~EN2), U4.7 (~EN3), U4.8 (~EN4)

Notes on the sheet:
ERC Flags
Boot options: BOOT0=0 BOOT1=x - Main flash memory boot BOOT0=1 BOOT1=0 - System memory boot (bootloader) BOOT0=1 BOOT1=1 - RAM memory
Mechanical
J3 - Pin Header JTAG Firmware Programming
Switch
J1 - PicoBlade SPI/POWER - 6 pins
LED
J4 - PicoBlade CAN - 3 pins
Boot Mode
BOOT0=0 BOOT1=0 - Main flash memory boot
Connectors
J5 - Pico Blade UART 3 pins
J2 - Pin Header - Image Sensor Connector
Flash Memory
CAN Transceiver
SPI: Flash and Sensor SPI2: SPI/POWER Pico Blade Connector
Microprocessor
Reset
I2C Pull-Up
Crystal

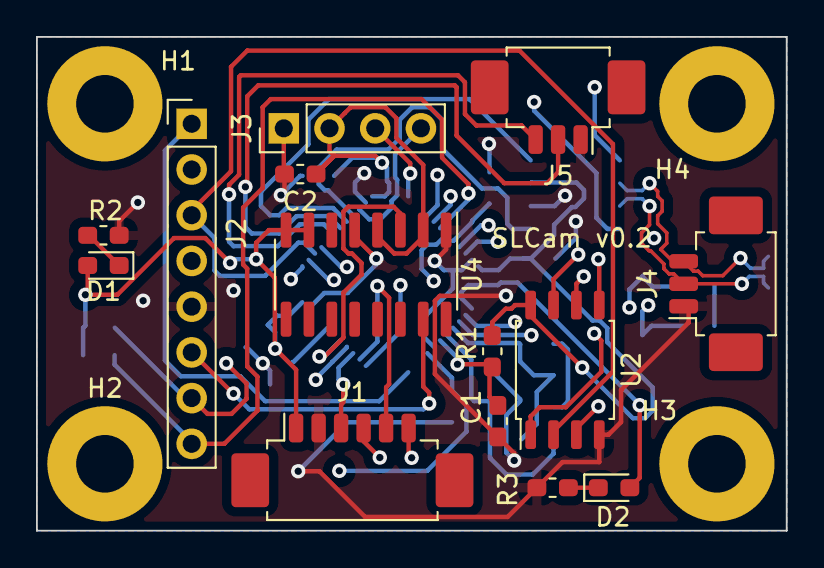
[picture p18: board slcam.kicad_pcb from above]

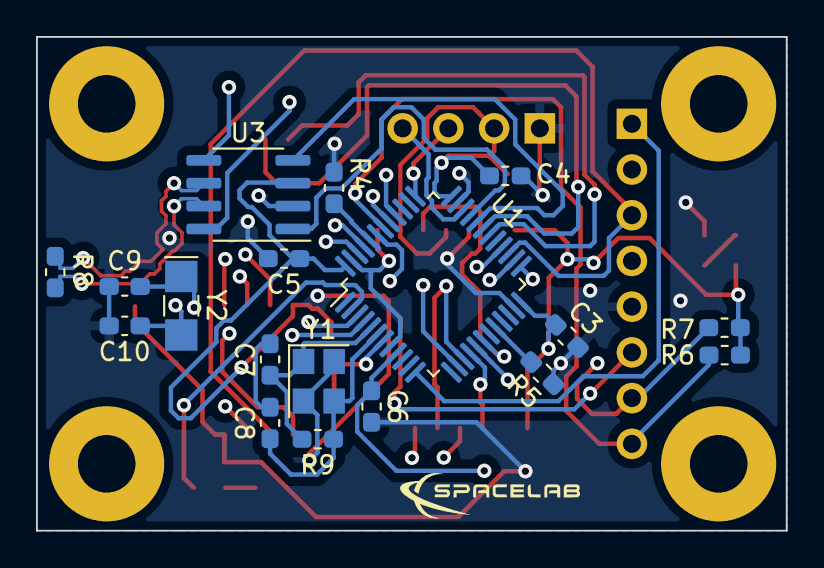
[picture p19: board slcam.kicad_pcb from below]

Board: 4 copper layers, 41.7 x 27.4 mm, 36 parts (18 on the bottom side), 38 nets.

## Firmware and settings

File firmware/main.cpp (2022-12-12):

/*
 * main.cpp
 * 
 * Copyright The SLCam Contributors.
 * 
 * This file is part of SLCam.
 * 
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
 */

/**
 * \brief Main file.
 * 
 * \author Gabriel Mariano Marcelino <gabriel.mm8@gmail.com>
 * \author Miguel Boing <miguelboing13@gmail.com>
 * 
 * \version 0.1.3
 * 
 * \date 2022/07/10
 * 
 * \defgroup main Main file
 * \{
 */

#include <hal/include/libopencm3/stm32/rcc.h>
#include <hal/include/libopencm3/stm32/gpio.h>

int main(void)
{
    rcc_periph_clock_enable(RCC_GPIOC);

    gpio_set_mode(GPIOC, GPIO_MODE_OUTPUT_2_MHZ, GPIO_CNF_OUTPUT_PUSHPULL, GPIO13);

    while(1)
    {
        for (int i = 0; i < 1000000; i++)
        {
            __asm__("nop");
        }

        gpio_toggle(GPIOC, GPIO13);
    }

    return 0;
}

/** \} End of main group */

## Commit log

2022-05-31 hardware: Adding a .gitignore for KiCAD projects
2022-05-31 hardware: Creating the KiCAD project
    [slcam.kicad_pcb, slcam.kicad_sch]
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2022-06-02 hardware: Minor fixes in the block diagram and BOM
2022-07-05 Add previous camera CAD model and camera case CAD model
    [Montagem Camera.SLDASM, Placa frontal camera.SLDPRT, Placa frontal camera_V2.SLDPRT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]
2022-07-05 add the previous camera_v2 CAD png
2022-07-08 Initial components placement #1 #4
    [slcam.kicad_pcb, slcam.kicad_sch, slcam.sch]
2022-07-08 Initial layout
    [slcam.kicad_pcb, slcam.sch]
2022-07-14 General fixes #8 #9
    [slcam.kicad_pcb, slcam.sch]
2022-08-19 mechanical: Renaming the mechanical project files following the organization standards. closes #16
    [slcam-back-shield-v2.sldprt, slcam-back-shield-v2.stl, slcam-back-shield.sldprt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]
2022-08-19 firmware: drivers: Initial structure of the OV2640 driver #22
2022-09-06 Developing schematics #11
    [slcam.sch]
2022-10-17 Fixing capacitors values and Crystal
    [slcam.sch]
2022-11-18 Initial layout and schematics fixes
    [slcam.kicad_pcb, slcam.sch]
2022-12-01 firmware: Adding crt assembly file
2022-12-02 firmware: driver: Importing the w25qxx driver from LibDriver #31
2022-12-02 firmware: drivers: w25qxxx: Initial structure of the stm32f103 interface #31
2022-12-02 firmware: drivers: w25qxxx: Initial Makefile #31
2022-12-02 firmware: drivers: Including the compilation of the w25qxxx driver #31
2022-12-06 Hardware: Developing Layout #23
    [slcam.kicad_pcb]
2022-12-09 firmware: Fixing the main file #27
    [main.cpp]
2022-12-10 firmware: drivers: Updating the main header
2022-12-26 Hardware: finishing layout, just missing footprints #23
    [slcam.kicad_pcb]
2022-12-26 firmware: drivers: uart: Creating uart header and source files #43
2022-12-28 firmware: drivers: uart: Init uart function #43
2022-12-28 firmware: Adding uart driver to compilation #43
2022-12-29 firmware: drivers: uart: Returning int in initialization #43
2022-12-29 firmware: drivers: uart: Implementing send and receive byte functions #43
2022-12-30 firmware: drivers: uart: Adding all function declarations #43
2023-01-05 firmware: Changing temporarily drivers rule #43
2023-01-23 hardware: Fixing the position of some labels in the layout #29
    [slcam.kicad_pcb]
2023-01-23 hardware: Improving PCB tracks #29
    [slcam.kicad_pcb]
2023-01-23 hardware: Fixing DRC warnings #29
    [slcam.kicad_pcb]
2023-01-23 hardware: Updating KiCad version and minor fixes in the schematics #29
    [slcam.kicad_sch, slcam.sch]
2023-01-23 hardware: Adding the project name/version and the SpaceLab logo to the PCB #23 #29 closes #38 closes #42
    [slcam.kicad_pcb]
2023-01-23 hardware: Adding a table with info about the PCB to the layout project #29
    [slcam.kicad_pcb]
2023-01-23 hardware: Adding renderizations of the PCB
2023-01-25 hardware: outputs: Updating the step model of the PCB
2023-01-25 hardware: Minor improvements in the schematics #28
    [slcam.kicad_sch]
2023-01-27 hardware: Adding the second part of the TPS2044D IC #28
    [slcam.kicad_sch]
2023-01-27 hardware: Updating the layout with the connections of the second part of the TPS2044D IC #28
    [slcam.kicad_pcb]
2023-02-07 hardware: Adding the PWR_FLAG to remove ERC errors #28
    [slcam.kicad_sch]
2023-02-07 hardware: Updating the metadata of the schematics #28
    [slcam.kicad_sch]
2023-02-07 hardware: Updating the metadata of the layout and fixing DRC errors
    [slcam.kicad_pcb]
2023-02-07 Disabling the PCB renderer in the PCB project workflow
2023-02-09 General fixes and improvements #45 #46 #47 #47 #48 #49 #50 #51
    [slcam.kicad_sch]
2023-02-11 hardware: fixing SPI pins #46
    [slcam.kicad_sch]
2023-02-11 hardware: fixing secong crystal schematics #45
    [slcam.kicad_sch]
2023-02-14 General fixes and improvements #45
    [slcam.kicad_sch]
2023-02-15 firmware: Adding stm32 family variable for opencm3 #24
2023-02-15 firmware: drivers: uart: Code improvements #43
2023-02-15 firmware: Adding libs to compilation chain #24
2023-02-15 firmware: drivers: uart: Queue uart functions with code optimizations #24
2023-02-28 firmware: drivers: uart: RX enable/disable implementation #43
2023-02-28 firmware: drivers: uart: Changing data to type uint16 accordingly to hal #43
2023-02-28 firmware: drivers: uart: uart_write implementation #43
2023-02-28 firmware: drivers: uart: Implementing error code handling #43
2023-03-03 hardware: finishing fixes and new components
    [slcam.kicad_pcb]
2023-03-07 hardware: Fixing ERC errors
    [slcam.kicad_sch]
2023-03-07 hardware: Fixing DRC errors and general improvements in the layout
    [slcam.kicad_pcb]
2023-03-08 hardware: Fixing the footprint of the 32 kHz crystal #45
    [slcam.kicad_pcb, slcam.kicad_sch]
2023-04-05 hardware: changing component values #52
    [slcam.kicad_pcb]
2023-04-05 hardware: finished bill of materials #52
    [slcam.csv]
2023-04-28 hardware: Removing bill of materials from README file
2023-04-28 hardware: schematics: Adding the partnumbers of some components #52
    [slcam.kicad_sch]
2023-04-29 hardware: schematics: Adding the partnumbers of components #52
    [slcam.kicad_sch]
2023-04-29 hardware: outputs: Updating the BOM. closes #52
    [slcam.csv]
2023-05-03 hardware: outputs: Addding the exported gerber and centroid files. closes #30 closes 33
    [slcam-B_Cu-v0.2.gbr, slcam-B_Mask-v0.2.gbr, slcam-B_Silkscreen-v0.2.gbr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]
2023-05-08 hardware: updating BOM #30
    [slcam.csv]
2023-05-09 hardware: fixing mouting holes
    [slcam.kicad_pcb]
2023-05-10 hardware: Fixing the partnumber of C3, C4, C5 and C6
    [slcam.csv, slcam.kicad_sch]
2023-05-10 hardware: layout: Minor fixes
    [slcam.kicad_pcb]
2023-05-10 hardware: fixing mounting holes
    [slcam.kicad_pcb]
2023-05-11 hardware: Fixing J2 position
    [slcam.kicad_pcb]
2023-05-11 hardware: Fixing the boot mode option (changing to main flash memory)
    [slcam.kicad_pcb, slcam.kicad_sch]
2023-05-11 hardware: Fixing the value of some capacitors
    [slcam.csv, slcam.kicad_sch]
2023-05-30 mechanical: Adding v0.2 step files
    [slb-slc-case-back.step, slb-slc-case-front.step, slcam-back-shield-v2.sldprt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]
2023-05-31 mechanical: Adding the project files from solidworks
    [slb-slc-case-back.step, slb-slc-case-front.sldprt, slb-slc-case-front.step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]
2023-05-31 mechanical: Adding technical drawnings
    [slb-slc-case-back.slddrw, slb-slc-case-front.slddrw]
2023-07-12 firmware: drivers: uart: Fixing the code style and minor improvements #43
2023-07-12 firmware: drivers: uart: Minor improvements and adding doxygen documentation #43
2023-07-20 firmware: importing i2c files from obdh2 #67
2023-07-29 firmware: drivers: uart: Improving the Makefile script #43
2023-07-29 firmware: doc: Adding the TCAN33x driver to the product tree #73
2023-07-29 firmware: drivers: Initial structure of the CAN driver #72
2023-07-29 firmware: drivers: Adding the CAN driver to the Makefile #72
2023-07-29 firmware: tests: mockups: drivers: Initial structure of the CAN driver mockup #72
2023-08-02 firmware: drivers: can: Partial implementation of the CAN driver #72
2026-06-14 Update documentation
    [UC-474(B0067).STEP, slb-slc-case-back.slddrw, slb-slc-case-back.step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]

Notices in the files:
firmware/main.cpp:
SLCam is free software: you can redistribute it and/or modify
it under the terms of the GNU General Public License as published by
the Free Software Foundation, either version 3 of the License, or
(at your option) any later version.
